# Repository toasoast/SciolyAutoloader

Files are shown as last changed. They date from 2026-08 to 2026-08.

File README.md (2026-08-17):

# Scioly Balsa Event Autoloader

This is my take on an autoloader used for Bridge, Boomilever, and Tower. It uses an aluminum extrusion frame, a 5 gallon water jug to hold the sand, and some printed parts for the spout.

<div align ="center">
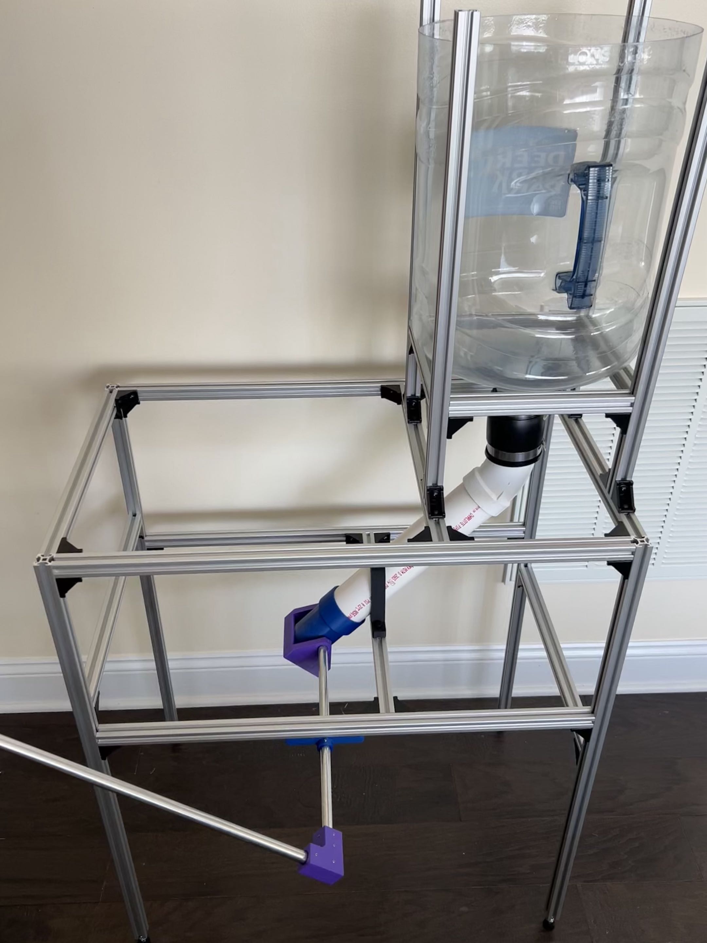
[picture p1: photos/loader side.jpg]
Side view of autoloader
  
  <p>Side view of the loader</p>
</div>

# Materials

## Part List

| Part | Qty | Price | Source |
|---|---|---|---|
| 2020 extrusion | See cut list | $112 | [tnutz.com](https://www.tnutz.com/product/exm-2020/) |
| 2020 M6 feet (optional) | 4 | $8 | [tnutz.com](https://www.tnutz.com/product/lf-020-a/) |
| 2020 corners + mounting hardware | Min. 36 | $26 | See below |
| 5 gal. water jug | 1 | $16 | See below |
| 1/2 in. aluminum rod | 2 | $10 | [Amazon](https://www.amazon.com/dp/B0GJHNZRNZ) |
| 2 in. x 12 in. PVC pipe | 1 | $8 | [Home Depot](https://www.homedepot.com/p/Charlotte-Pipe-2-in-x-2-ft-PVC-DWV-Schedule-40-Pipe-PVC072000200HA/100585960) |
| 2 in PVC 45 deg elbow | 1 | $3 | [Home Depot](https://www.homedepot.com/p/NIBCO-2-in-PVC-DWV-45-Degree-Hub-x-Hub-Elbow-C4806HD2/100346919) |
| 2 in PVC flexible adapter | 1 | $7 | [Home Depot](https://www.homedepot.com/p/Fernco-2-in-x-2-in-DWV-Flexible-PVC-Coupling-P1056-22/100096490) |
| Set screws | 20 | $7 | See below |
| 3d printed parts | See below | See below | Printer |
| M5x16 screws | 4 | $5 | [Amazon as an example](https://www.amazon.com/dp/B0DGXWZJP2) |
| Total | | ~$200 | |

Extrusion: The cheapest source I could find for cut extrusion was from [tnutz.com](https://www.tnutz.com). If you have means to cut it yourself and have, say, a robotics team that you could steal extrusion from, 

Mounting hardware: I used 44 corner brackets on my final build but unfortunately the cheapest packs on Amazon come as 40 pieces. You can get away with only using 36 brackets, leaving you with 4 extra T-nuts to screw on the rod and pipe holders. [Here](https://www.amazon.com/dp/B0FFMQ9NPP) is a link to 40 brackets, [here](https://www.amazon.com/dp/B0GF89B14F) is a link to 30 with a cheaper unit price that you could get two of to have some extra.

Water jug: This is best sourced locally, most grocery stores carry this. You might be able to find one for less that $16. It should be something similar to [this](https://www.homedepot.com/p/Primo-Primo-5-Gal-Water-with-Empty-Exchange-1008778394/205216096).

Set screws: I happened to have #4-40x1/4" set screws on me, so that's what I designed this around. However, any similarly sized set screw should work. [Here](https://www.amazon.com/dp/B0CY972RP7) is the one I used, but use whatever you have or is cheapest on Amazon at the time.

## Cut List

| 2020 Extrusion Length | Qty |
|---|-----|
| 30 in | 4 |
| 15 in | 6 |
| 25 in | 4 |
| 20 in | 4 |
| 8 in | 4 |

If you're looking to install feet and are ordering from tnutz, choose the M6 x 1.0 x 25mm deep tap option on one end when ordering the 30 in extrusion pieces.

## 3D Printed Parts

[Download link](https://github.com/toasoast/Autoloader/releases/download/v1.0.0/3dfiles.zip)

Printing tips: the spout, shaft collars (you need 2), pipe holder, and rod holder have pretty loose tolerances. Printing the cap and corner in PETG is recommended since these parts experience a torque. The corner can crack if the set screws are overtightened, use more walls than you normally would.

If you want to use different set screws, STEP files of parts with generic 1 mm holes where set screws should go are provided.

The holes on the pipe and rod holders are sized for M5x16 screws (standard T-nut size).

# Assembly

<div align ="center">
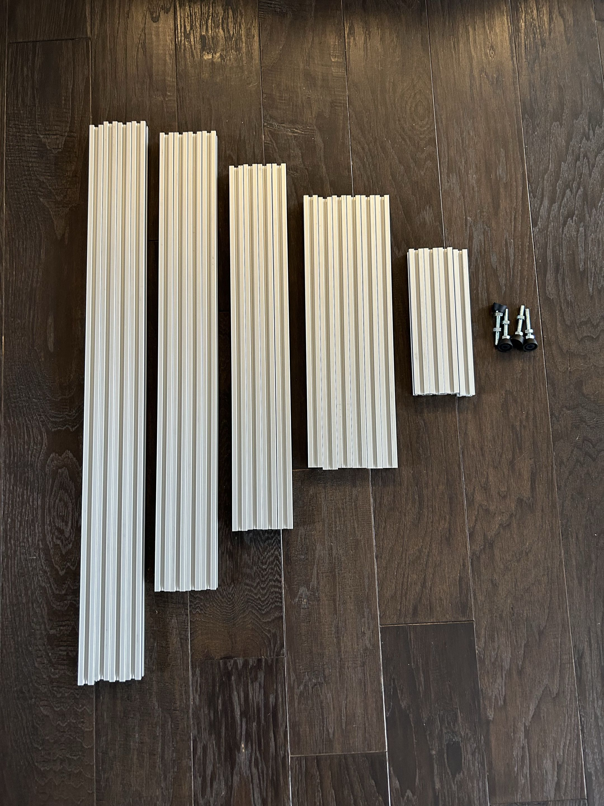
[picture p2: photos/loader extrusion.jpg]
Aluminum extrusion
  
  <p>tnutz.com order</p>
</div>

<div align ="center">
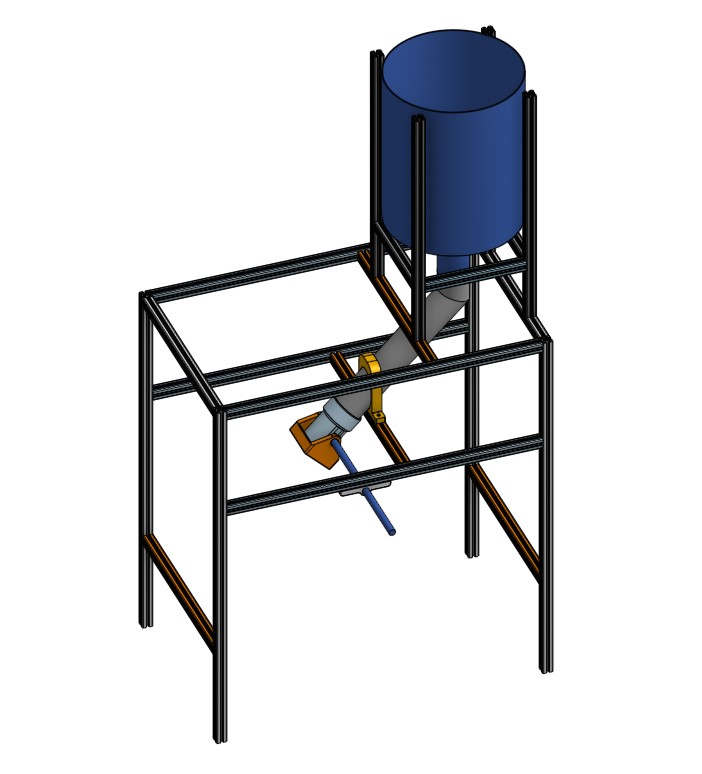
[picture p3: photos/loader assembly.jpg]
Loader assembly
  
  <p>3D model of the assembly</p>
</div>

The easiest way to cut the bottom off the water jug I found was with a standard utility knife. Attach the 45 degree PVC elbow using the flexible coupling.

For the frame, start with general shape, don't worry about the exact alignment. Make sure that you add two T-nuts each to the extrusion in the middle that the pipe holder sits on and to the bottom of the side extrusion that the rod holder hangs under (4 total). See the assembly for clarification. 

The 30 in extrusions are the legs, the 25 in extrusions are the long side, the 15 in extrusions are the short side, the 20 in extrusions are the legs of the jug holder, and the 8 in extrusions are the sides of the jug holder. I assembled the jug holder part separately from the rest of the frame and attached it, but it may be easier to assemble it directly on the frame as getting it into the T-nuts was kind of difficult. The 8 optional corner brackets that I used are the 4 at the top of each leg that connects the two side pieces, and 4 where the jug holder attaches (you can use one corner per leg instead of two).

<div align ="center">
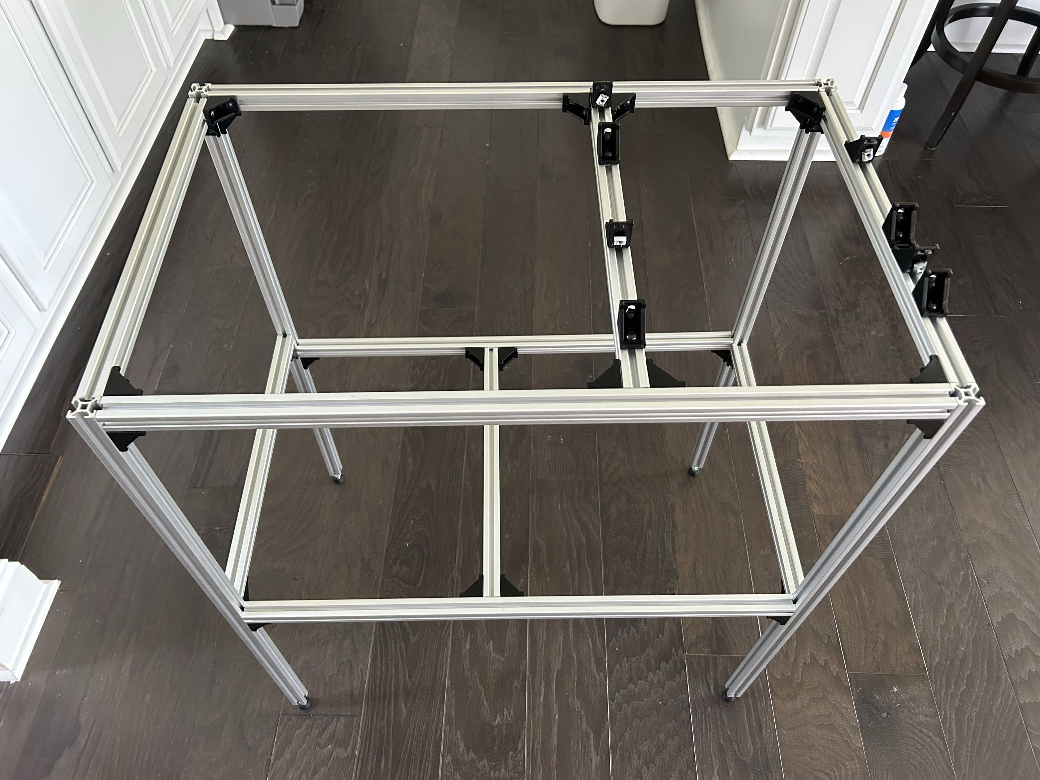
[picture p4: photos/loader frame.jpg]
Frame of the loader
  
  <p>Frame mid-assembly</p>
</div>

Once you have the general shape of the frame assembled, drop the water jug assembly in and connect the PVC pipe. Adjust the sides of the jug holder so the top of the water jug is roughly around the same height or below the top of the 20 in extrusions. Slide the printed pipe holder onto the pipe and screw it into the T-nuts using the M5x16 screws. Adjust the extrusions (vertically and horizontally) so that the pipe is naturally resting at 45 degrees.

<div align ="center">
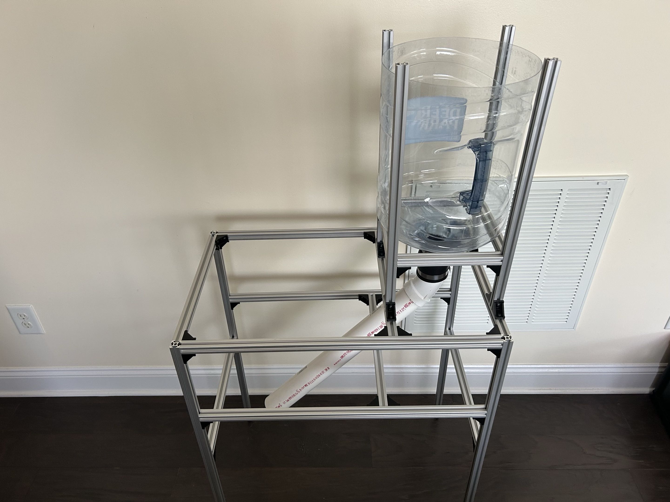
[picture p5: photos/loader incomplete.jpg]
Loader mid-assembly
  
  <p>The loader with uncut pipe</p>
</div>

The axle assembly should be done separately. The printed corner takes 12 set screws, the cap has 6, and each shaft collar has one. Assemble the cap, spout, shaft collars, and rod holder onto one of the rods. Tighten the set screws on the cap but leave the ones on the shaft collars loose. Attach the spout to the end of the PVC pipe and attach the rod holder to the T-nuts previously inserted into the frame using two M5x16 screws. Adjust the position of the rod holder on the frame and the position of the extrusions as needed until the rod goes through the spout straight and it rotates freely. Tighten down the set screws on the shaft collars and the screws in the extrusion corner brackets.

<div align ="center">
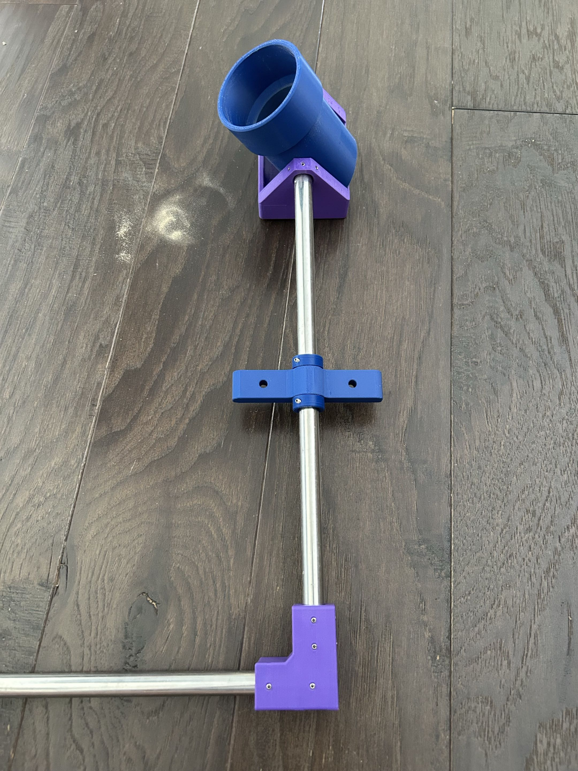
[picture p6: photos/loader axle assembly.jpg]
Axle assembly
  
  <p>The axle of the loader</p>
</div>

<div align ="center">
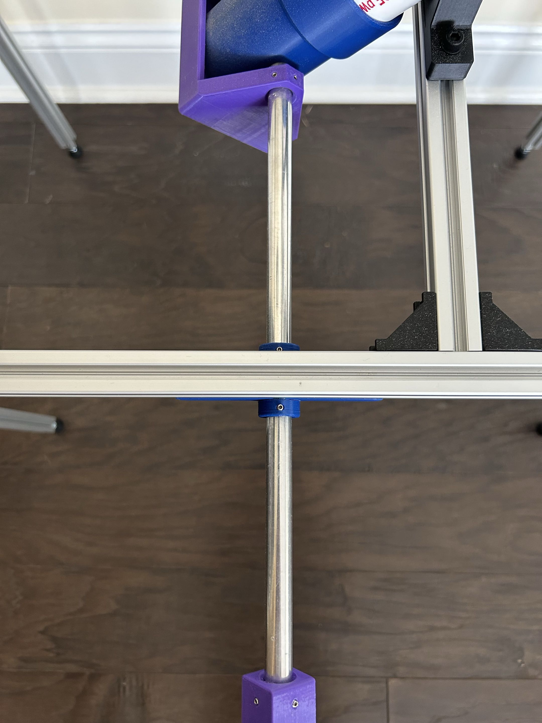
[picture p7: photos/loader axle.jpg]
Axle assembled
  
  <p>Installed axle</p>
</div>

<div align ="center">
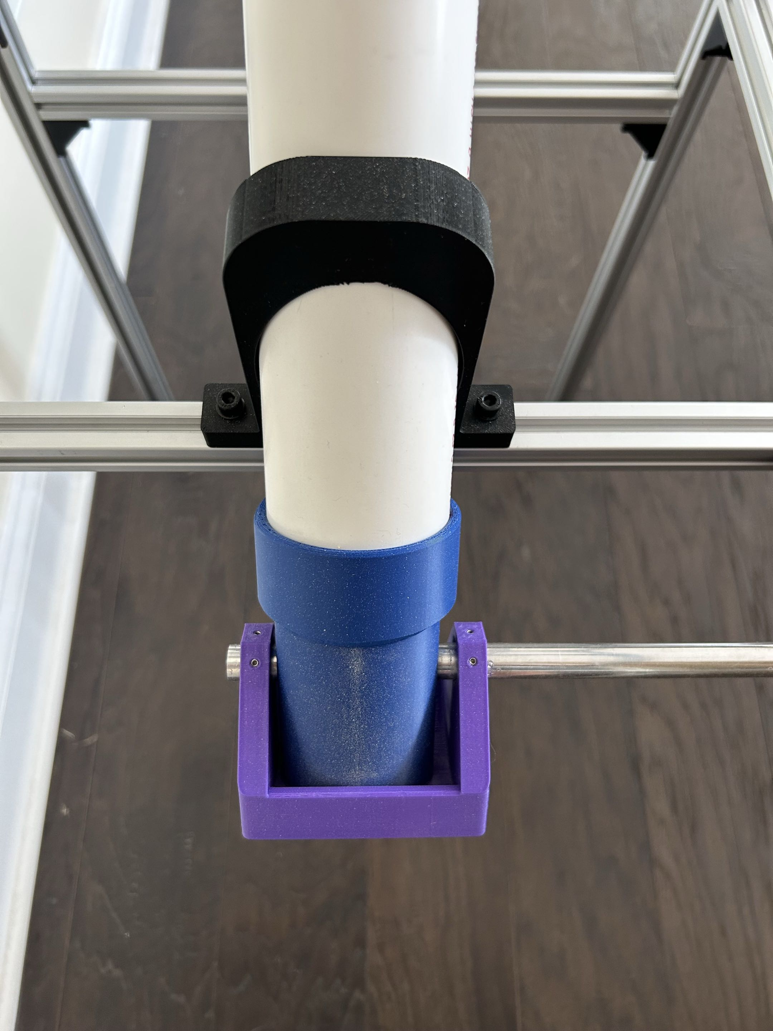
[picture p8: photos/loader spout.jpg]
Loader spout
  
  <p>Spout of the loader</p>
</div>

Separately, insert the other rod into the printed corner. This rod will act as the handle and should go in the end with 4 set screws. The axle will connect to the end with 8 set screws. Depending on your printer's tolerance, this may be quite tight, I had to use a mallet to install the handle into the corner. Then, you can install the corner onto the exposed end of the axle. Tighten down the set screws (don't overtighten though since they corner can crack!). You should now be able to open the spout with the handle.

<div align ="center">
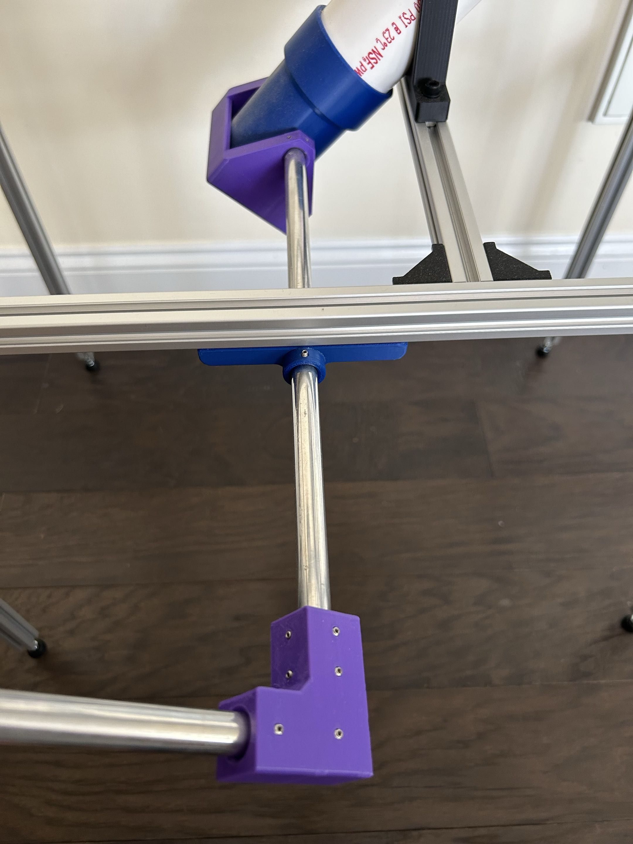
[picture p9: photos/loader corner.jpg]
Axle corner
  
  <p>The installed corner</p>
</div>

Here's some final photos:

<div align ="center">
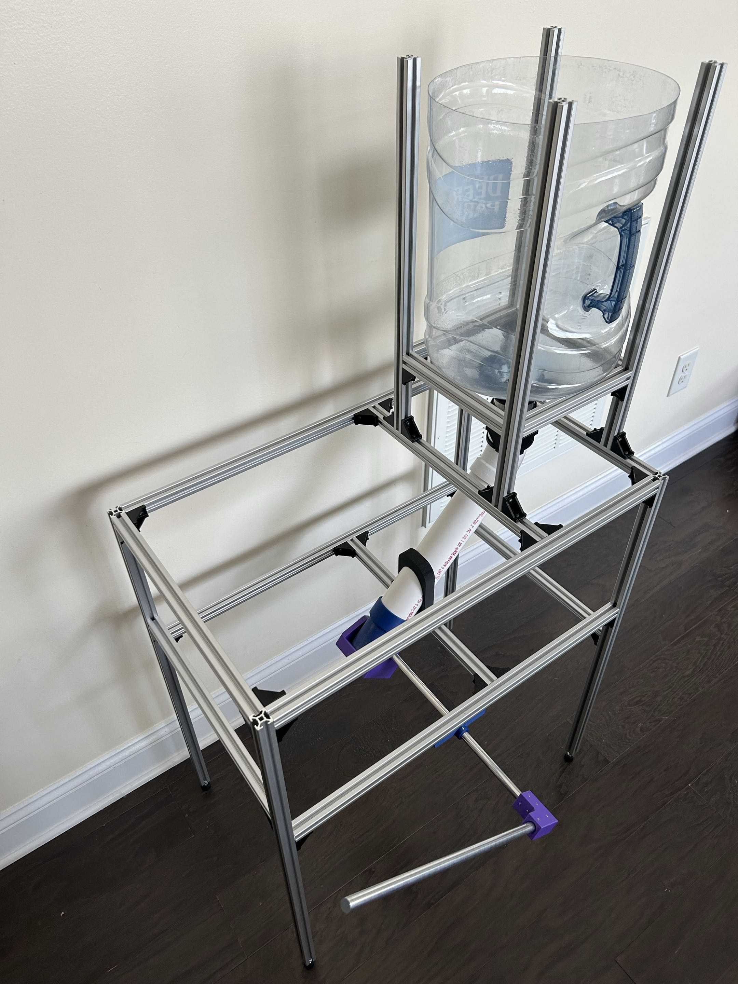
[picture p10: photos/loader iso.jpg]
View of the complete loader
  
  <p>The completed loader!</p>
</div>

<div align ="center">
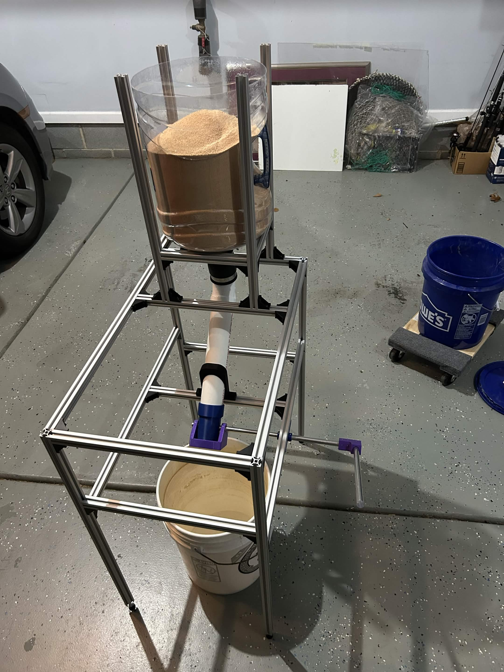
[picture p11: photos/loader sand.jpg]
Loader with sand
  
  <p>Test with sand</p>
</div>

# Credits

Thanks to members of the Balsa Engineering server for idea inspiration and with several design aspects.

Updated August 2026

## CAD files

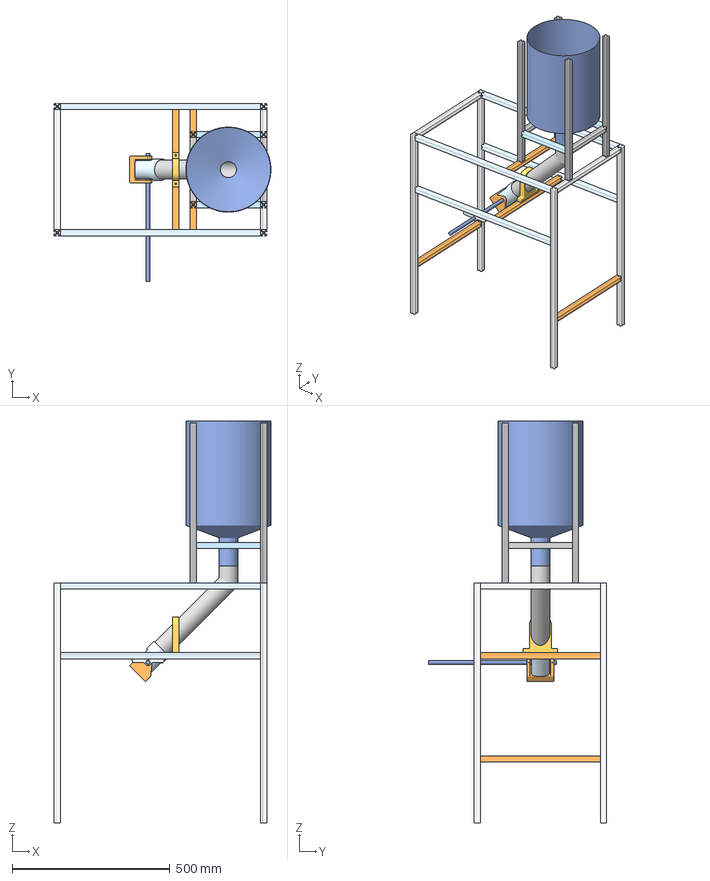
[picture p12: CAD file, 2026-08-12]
3dfiles/assembly.3mf
688.4 x 566.1 x 1275.6 mm

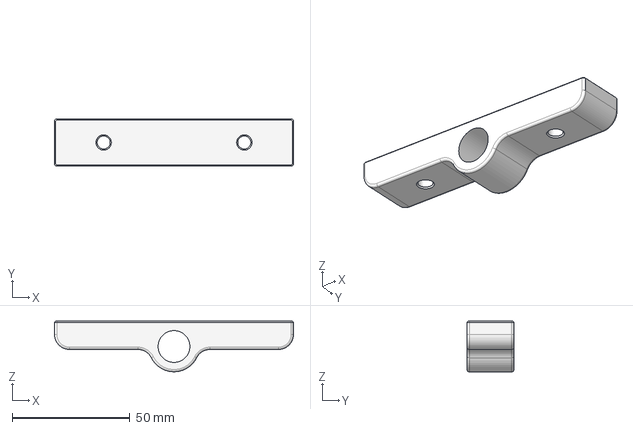
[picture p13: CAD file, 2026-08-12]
3dfiles/rod holder.step
101.4 x 20.0 x 21.5 mm

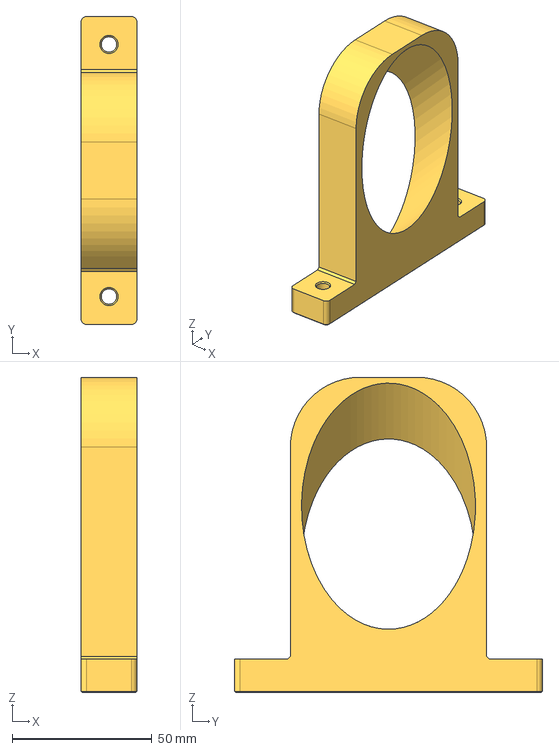
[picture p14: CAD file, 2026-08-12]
3dfiles/pipe holder.step
20.0 x 110.3 x 113.0 mm

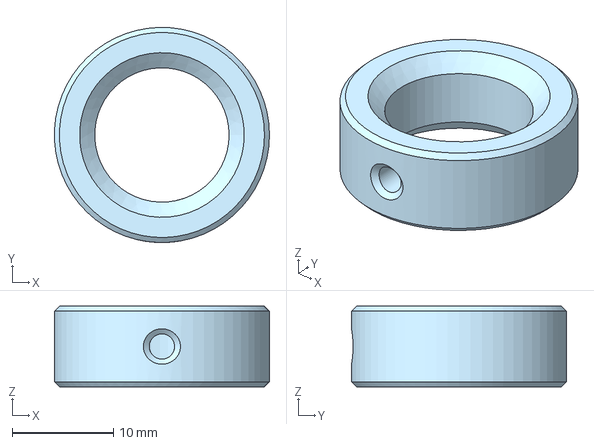
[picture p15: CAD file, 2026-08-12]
3dfiles/shaft collar.step
21.3 x 21.3 x 8.00 mm

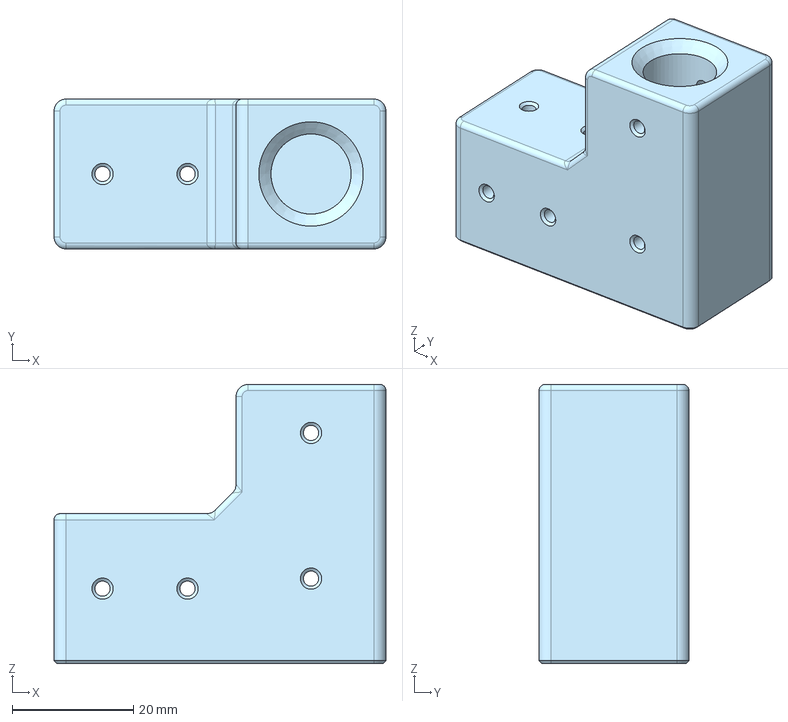
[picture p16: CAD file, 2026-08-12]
3dfiles/corner.step
54.7 x 24.7 x 46.0 mm

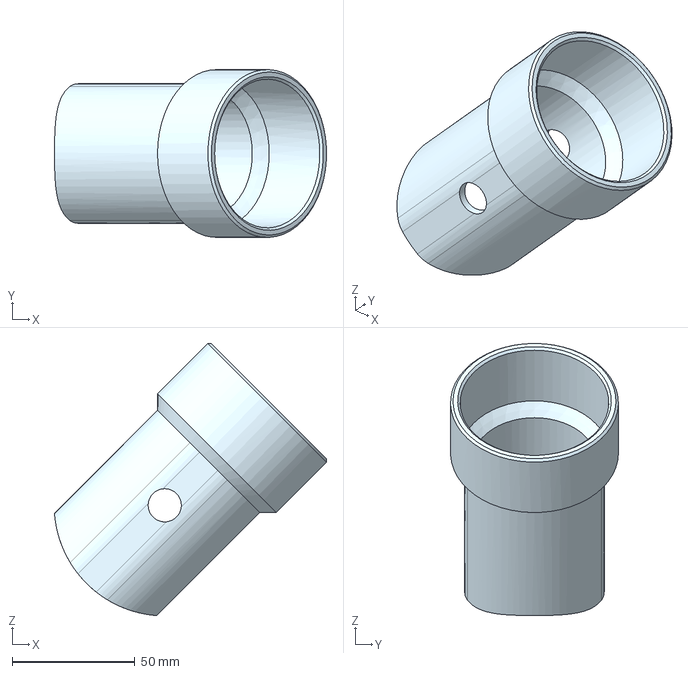
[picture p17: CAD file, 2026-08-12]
3dfiles/spout.step
110.7 x 68.3 x 110.8 mm

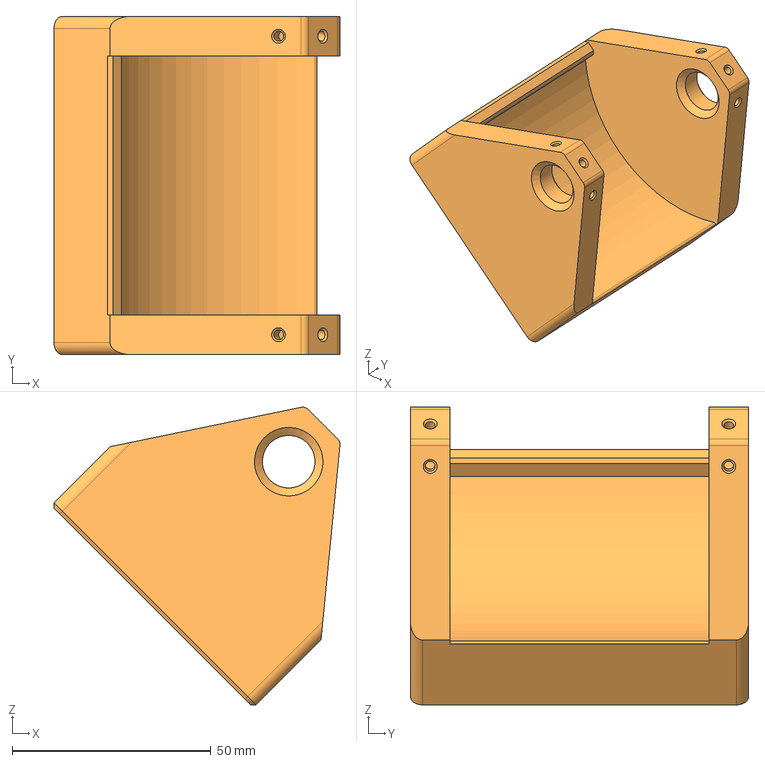
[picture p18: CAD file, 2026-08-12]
3dfiles/cap.step
71.9 x 85.0 x 74.8 mm

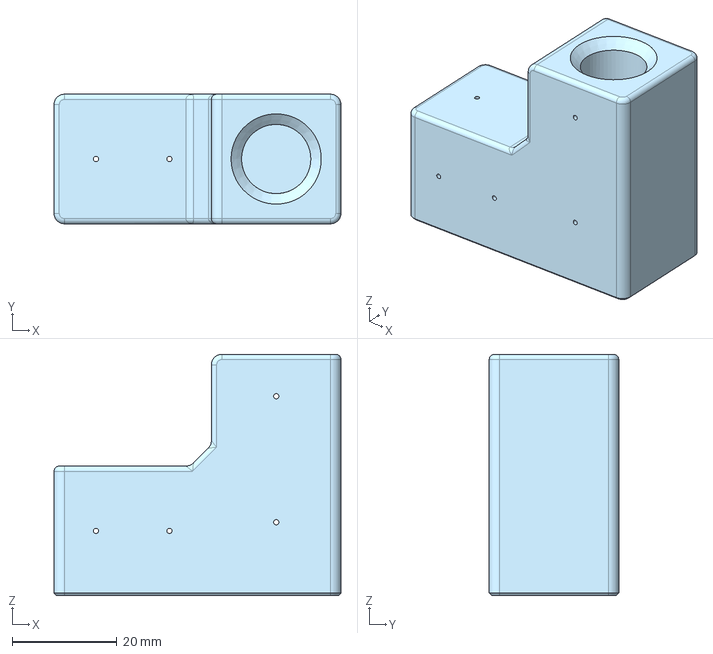
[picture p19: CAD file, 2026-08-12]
3dfiles/no set screws/corner no set screw.step
54.7 x 24.7 x 46.0 mm

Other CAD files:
3dfiles/no set screws/shaft collar no set screw.step
3dfiles/no set screws/cap no set screw.step
3dfiles/stl/cap.stl
3dfiles/stl/corner.stl
3dfiles/stl/pipe holder.stl
3dfiles/stl/rod holder.stl
3dfiles/stl/shaft collar.stl
3dfiles/stl/spout.stl

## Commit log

2026-08-12 Rename 3dfiles/shaft collar.stl to 3dfiles/stl/shaft collar.stl
    [shaft collar.stl]
2026-08-12 Rename 3dfiles/corner no set screw.step to 3dfiles/no set screws/corner no set screw.step
    [corner no set screw.step]
2026-08-12 Rename 3dfiles/cap no set screw.step to 3dfiles/no set screws/cap no set screw.step
    [cap no set screw.step]
